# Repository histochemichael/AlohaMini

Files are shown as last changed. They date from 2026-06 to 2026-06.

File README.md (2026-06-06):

# AlohaMini2
 

AlohaMini2 is a dual-arm mobile robot with a motorized vertical lift — a major generational upgrade over AlohaMini1 while keeping the self-build BOM under $1,000.  

Fully 3D-printable on a Bambu P2S, built for embodied AI research, and priced for anyone serious about real-world manipulation.

> Assemble at home in ~120 minutes. Train or deploy with LeRobot.

## Updates

- [2026-06-06] AlohaMini2 released — 70 kg base load, 30 kg lift, 1 kg arm payload, 6+1 DoF, 52 cm reach, under $1,000 self-build BOM
- [2026-02-26] Fine-tuning and deployment guide for Pi 0.5 on AlohaMini (`examples/pi0.5_openpi`)
- [2025-12-18] URDF and simulation assets available (`AlohaMini1/simulation/src/Aloha/`)
- [2025-11-27] STEP (CAD) files available (`AlohaMini1/hardware/mobile_base/step/`)

## What's New in AlohaMini2

### Architecture

| | AlohaMini | AlohaMini2 |
|---|---|---|
| Arm system | [SO-ARM100 / SO-ARM101](https://github.com/TheRobotStudio/SO-ARM100) | [AM-ARM200](https://github.com/liyiteng/AM-ARM) |
| Mobile base system | [mobile_base1](AlohaMini1/hardware/mobile_base/) | [mobile_base2](AlohaMini2/hardware/mobile_base2/) |
| Printer requirement | Large-format FDM (>= 380 mm bed) | Bambu P2S (consumer-grade) |

### Performance

| | AlohaMini | AlohaMini2 |
|---|---|---|
| Base max load | 10 kg | 70 kg  |
| Lift capacity | 5 kg | 30 kg |
| Lift stability | Standard | Significantly reinforced |
| Arm payload | 0.3 kg | 1 kg |
| Arm reach | 40 cm | 52 cm |
| Arm DoF | 5+1 | 6+1 |
| Cameras | 5 | 5 (forward, backward, chest, dual wrist) |

AlohaMini2 is LeRobot-ready out of the box and remains fully open-source — hardware CAD, URDF, and software included.

## Gallery

<p align="center">
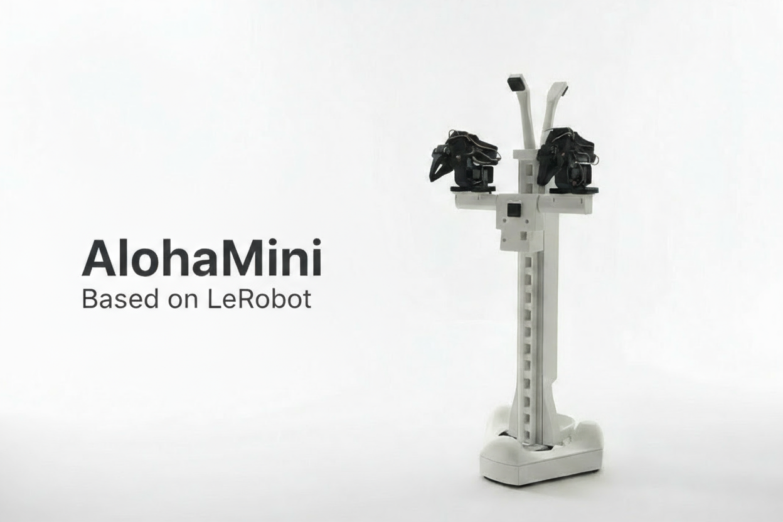
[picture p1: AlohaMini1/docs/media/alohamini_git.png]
  
</p>

## Bill of Materials (BOM)

| Component | Model / Notes | Qty | Unit Price (USD) |
|---|---|-----|---|
| Servo — standard | Feetech STS-3215 (12V, follower arms + base) | 11 | ~$16 |
| Servo — high-torque | Feetech STS-3095 (12V 95 kg·cm, lift + arm power joints) | 7 | ~$50 |
| Bus servo controllers | Waveshare | 2 | ~$5 |
| Compute | Raspberry Pi 5 (2 GB) | 1 | ~$93 |
| Cameras | 720p USB, 2.4 mm focal length | 5 | ~$17 |
| Omni wheels | 127 mm (74A) | 3 | ~$40 |
| Battery 12V | 11200 mAh Li-ion | 2 | ~$16 |
| Frame | 3D-printed on Bambu P2S | — | ~4 kg filament |
| **Total** | — | — | **~$950** |

> Full BOM with CN/US buy links: **[AlohaMini2/docs/BOM.md](AlohaMini2/docs/BOM.md)**  
> Compute can be swapped for Jetson Orin Nano or any SBC with USB 3.0.  

## Quick Start

1. **BOM** — review the component list and source parts  
   See **[Bill of Materials](AlohaMini2/docs/BOM.md)**

2. **3D Printing** — print all structural parts (~4 kg filament, Bambu P2S)  
   See **[Print Guide](AlohaMini2/docs/BOM.md#3d-printing)**

3. **Assembly** — build in ~60 minutes (arms pre-assembled)  
   See **[Assembly Guide](AlohaMini2/docs/assembly_guide.md)**

4. **Software setup & teleoperation** — install, connect, control  
   See **[Software Guide](software)**

## Product Line

| Model | Servo System | Chassis | Best For | Official Store (CN) |
|---|---|---|---|---|
| **AlohaMini2** | STS-3215 standard servos | 3D-printed base | Self-build research and development | [Taobao](https://item.taobao.com/item.htm?abbucket=9&id=1015799132286) |
| **AlohaMini2 Pro** | STS-3250 industrial-grade servos | Metal-reinforced base | Higher-duty research and lab use | [Taobao](https://item.taobao.com/item.htm?abbucket=9&id=1015799132286) |

## Contact

Email: liyiteng+github@gmail.com  
WeChat: liyiteng  
Videos & tutorials: Bilibili / YouTube / TikTok

## Team

AlohaMini is created by **Li Yiteng** and **Wu Zhiyong**.

## Acknowledgements

Thanks to the open robotics community:  
**ALOHA · LeKiwi · SO-ARM100 · SO-ARM100-Track-Axis · Pi-0.5 · LeRobot · Hugging Face**

## Support AlohaMini

If you find this project useful:
- Star the repo
- Follow for updates
- Join the community on Discord

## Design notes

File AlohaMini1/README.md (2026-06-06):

# AlohaMini
 

AlohaMini is a dual-arm mobile robot with a motorized vertical lift — beautifully designed, fully 3D-printable, and affordable.  

Built for embodied AI research and real-world manipulation. Assemble at home in ~60 minutes, customize every part, and train or deploy with LeRobot.

Note:
Use ROS only if you need URDF visualization, RViz inspection, or Gazebo simulation.

## Updates

- [2026-02-26] Update the fine-tuning and deployment guide for Pi 0.5 on Alohamini ('examples/pi0.5_openpi')
- [2025-12-18] URDF and simulation assets are now available for visualization and simulation (`simulation/src/Aloha/`)
- [2025-11-27] STEP (CAD) files are now available (`/hardware/mobile_base/step/`)

### What Makes It Different

- **Motorized vertical lift** — 0–60 cm travel (floor-to-table reach)
- **5-camera perception system** — top, front, back, and dual arm cameras engineered for embodied-AI reproducibility
- **Completely open-source** — hardware and software freely available
- **LeRobot-compatible** — works out of the box
- **Clean, modern design** — built for both function and aesthetics
- **Low-cost & accessible** — engineered so anyone can build a capable robot at home

## 📸 Gallery

<p align="center">
  
</p>

## ⚙️ Bill of Materials (BOM)
### Main Components

| Component | Model / Notes | Qty | Unit Price (USD) |
|---|---|-----|---|
| Servo motors | Feetech STS3215 (12V bus) | 16 | $13.89 |
| Motor control boards | Waveshare Bus Servo Adapter (A) | 2 | $10.55 |
| Compute platform | Raspberry Pi 5 (4/8GB) | 1 | $80 |
| Cameras | 720p USB cameras (2 for arms, 3 for mobile base) | 5 | $20 |
| Mobility system | Omni wheels | 3 | $36.00 |
| Battery | 12V Li-ion pack | 2 | $32.99 |
| Frame | 3D-printed body (ABS / PETG / PLA) | — | ~4kg filament (self-print) |
| **Total** | — | — | **~$600 (self-print)** |

Note: 
- Printable STL files under `/hardware/`
- Compute platform can be replaced with Jetson Nano or similar SBCs if desired.
- URDF files will be released soon

## Quick Start

Start building and running AlohaMini:

1. **Hardware acquisition** — Purchase components and 3D print parts  
   See **[BOM & 3D-Print](docs/BOM.md)**

1. **Assembly** — build the robot in ~60 minutes (SO-ARM pre-assembled)  
   See **[assembly guide](docs/hardware_assembly.md)**

1. **Software setup & teleoperation** — install, connect, and control the robot  
   See **[software guide](software)**

##  Product Line
| Model | Build | Rigidity | Target Users | Official Store (US) | Official Store (CN) |
|---|---|---|---|---|---|
| **AlohaMini** | Fully 3D-printed | Standard | Education, makers, research labs, home builds | - | [taobao](https://item.taobao.com/item.htm?abbucket=9&id=1015799132286) |
| **AlohaMini Pro** | Hybrid **3D-print + metal** | **~3×–5× stiffer** | Researchers needing plug-and-play, stable hardware | - | [taobao](https://item.taobao.com/item.htm?abbucket=9&id=1015799132286) |

> Same URDF & control stack across both versions — only structural materials differ.  
> Official store links are optional purchase channels for complete robots / kits.  
> AlohaMini remains open-source and can be self-built from the BOM, 3D-print files, and assembly docs.  

## Contact
Email: liyiteng+github@gmail.com  
WeChat: liyiteng  
Videos & tutorials soon on: Bilibili / YouTube / TikTok

## Team
AlohaMini is created by:  
**Li Yiteng** / **Wu Zhiyong**

##  Acknowledgements
Thanks to the open robotics community:  
**ALOHA · LeKiwi · SO-ARM100 · SO-ARM100-Track-Axis · Pi-0.5 · LeRobot · Hugging Face**

## ⭐ Support AlohaMini
If you like this project:
- ⭐ Star the repo  
- 🔔 Follow updates  
- 💬 Join the community

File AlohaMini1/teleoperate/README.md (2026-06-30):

# AlohaMini1 Teleoperation

This folder packages the scripts used to teleoperate an AlohaMini1 with:

- a Raspberry Pi controlling the mobile base, lift, and follower arms
- a PC controlling pedals/keyboard, phone or face steering, and SO-101 leader arms
- HTTP links between the PC and Pi

No personal IP addresses, Windows COM ports, or Pi `/dev/serial/by-id` paths are hardcoded in the commands. Replace placeholders such as `<PI_IP>`, `<PC_WIFI_IP>`, and `<LEFT_FOLLOWER_PORT>` with values from your own robot.

## Folder layout

```text
teleoperate/
  pc/
    combined_gyro_pedal_control_remote.py   # PC sender for base/lift plus gyro or face steering
    so101_leader_http_sender.py             # PC sender for one SO-101 leader arm
  pi/
    aloha_pi_follower_agent_pyserial.py     # Pi receiver for base/lift servos
    so101_follower_http_agent.py            # Pi receiver for one SO-101 follower arm
    aloha_camera_dashboard.py               # Optional Pi camera dashboard and recorder
  templates/
    commands.md                             # Copy/paste command templates with placeholders
    pi_ports.md                             # How to discover stable Pi serial ports
  requirements-pc-pedals.txt
  requirements-pi-base.txt
```

## Network architecture

```text
PC pedals/keys/steering -> Pi port 9000 -> base and lift
PC left leader arm      -> Pi port 9011 -> left follower arm
PC right leader arm     -> Pi port 9012 -> right follower arm
optional Pi cameras     -> Pi port 9100 -> browser dashboard
```

Run each receiver/sender in its own terminal while bringing the robot up. After the setup is stable, these commands can be wrapped in shell or batch scripts.

## What you must provide

These files do not include robot-specific calibration or hardware identity data. Each user must provide:

- Raspberry Pi IP address, found on the Pi with `hostname -I`
- PC Wi-Fi IPv4 address, found on Windows with `ipconfig`
- Pi serial paths, found with `ls -l /dev/serial/by-id/`
- Windows leader arm COM ports, found with `lerobot-find-port` or Device Manager
- LeRobot calibration files/IDs for each SO-101 leader and follower arm
- correct base/lift servo IDs and signs for your wiring
- optional camera `/dev/v4l/by-path/...` names if using the camera dashboard

The working prototype used base servo IDs `9`, `8`, `10` and lift ID `11`, but do not assume those match your robot.

## Optional hardware references

These are not strict requirements; they are examples of hardware used during bring-up or hardware in the same style.

- USB foot pedals for base/lift keyboard input: [Amazon example](https://www.amazon.com/dp/B0B1ZJVZ2K?ref=ppx_pop_mob_ap_share)
- Phone holder / VR-style adapter for phone steering: [Amazon example](https://www.amazon.com/dp/B0B1ZJVZ2K?ref=ppx_pop_mob_ap_share)
- Webcam for face steering: [Logitech C270 HD webcam](https://www.amazon.com/Logitech-Desktop-Widescreen-Calling-Recording/dp/B004FHO5Y6)

Any equivalent device should work if it presents itself to the PC as keyboard input for pedals, or securely holds the phone while the browser page streams orientation data.
<p align="center">
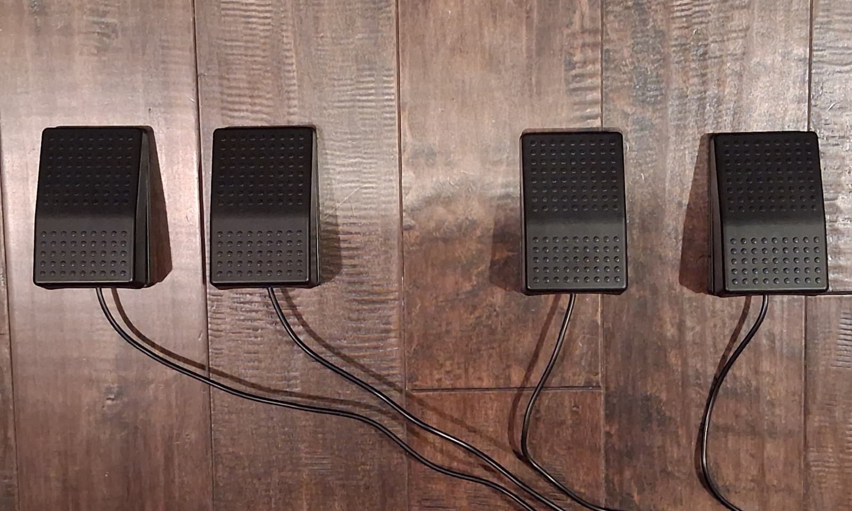
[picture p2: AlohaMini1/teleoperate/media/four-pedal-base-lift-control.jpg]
Four USB pedals for base and lift control
  
  <br>
  <sub>Four-pedal base and lift control layout.</sub>
</p>

## Dependencies

### Raspberry Pi

Use the same Python environment that has LeRobot working for your follower arms. Install base/lift dependencies:

```bash
python3 -m pip install -r requirements-pi-base.txt
```

The arm receiver also needs LeRobot and the Feetech/scservo SDK stack used by SO-101 followers. If your LeRobot install reports `scservo_sdk` errors, reinstall the Feetech-enabled LeRobot dependencies for your version.

The optional camera dashboard requires `ffmpeg`:

```bash
sudo apt update
sudo apt install ffmpeg
```

### PC

Use the same conda environment that has LeRobot working for your leader arms. For the pedal/keyboard/steering sender:

```bat
python -m pip install -r requirements-pc-pedals.txt
```

`opencv-python`, `mediapipe`, and `numpy` are only needed for `--steering-mode face`. Phone gyro steering and keyboard/pedal control need `pynput`.

## Calibration files

LeRobot looks up calibration by the `--robot-id` or `--leader-id` you pass to the scripts. If follower arms move from the PC to the Pi, copy the follower calibration files from the PC to the Pi.

Typical PC location:

```text
C:\Users\<YOU>\.cache\huggingface\lerobot\calibration\robots\so_follower\
```

Typical Pi location:

```bash
~/.cache/huggingface/lerobot/calibration/robots/so_follower/
```

Example copy command from Windows:

```bat
scp "C:\Users\<YOU>\.cache\huggingface\lerobot\calibration\robots\so_follower\<FOLLOWER_ID>.json" <PI_USER>@<PI_IP>:/home/<PI_USER>/.cache/huggingface/lerobot/calibration/robots/so_follower/
```

Leader calibration files stay on the PC if the leader arms stay plugged into the PC.

## Bring-up order

1. Put the robot on blocks or otherwise make it safe before first motion.
2. Start the Pi base/lift receiver and verify `curl http://127.0.0.1:9000/status`.
3. Start one Pi follower arm receiver and verify `curl http://127.0.0.1:9011/status`.
4. Start the matching PC leader sender at low FPS, e.g. `--fps 10`.
5. Move the leader slowly and confirm direction/range.
6. Repeat for the second arm on port `9012`.
7. Start the PC base/lift/steering sender.
8. Only after each channel works independently should you operate base, lift, and both arms together.

## Command templates

See [`templates/commands.md`](templates/commands.md) for full copy/paste commands.

The most important placeholders are:

```text
<PI_IP>                    Raspberry Pi IP from hostname -I
<PC_WIFI_IP>               Windows Wi-Fi IPv4 from ipconfig
<BASE_LIFT_PORT>           Pi /dev/serial/by-id path for the base/lift servo bus
<LEFT_FOLLOWER_PORT>       Pi /dev/serial/by-id path for the left follower arm
<RIGHT_FOLLOWER_PORT>      Pi /dev/serial/by-id path for the right follower arm
<LEFT_LEADER_COM_PORT>     Windows COM port for the left leader arm
<RIGHT_LEADER_COM_PORT>    Windows COM port for the right leader arm
```

## Phone steering notes

The phone gyro page is served by the PC sender at:

```text
http://<PC_WIFI_IP>:8765
```

A phone holder or VR-style adapter can make phone steering easier to keep centered while driving. One example is listed in [Optional hardware references](#optional-hardware-references).

Android Chrome may block device orientation on insecure HTTP origins. If motion events are unavailable, either allow sensors for that site in Chrome settings, use face steering, or add a touch/slider steering fallback.

## Face steering notes

Face steering uses the PC camera and these main parameters. A standard USB webcam works; the optional hardware list includes one example used for this style of setup:

```text
--steering-mode face
--face-camera 0
--face-deadband 15
--face-max-yaw 40
--face-smoothing 0.2
--face-preview
```

Increase `--face-deadband` if tiny head movements cause unwanted turning. Increase/decrease `--turn-speed` to scale robot turning speed.
<table>
  <tr>
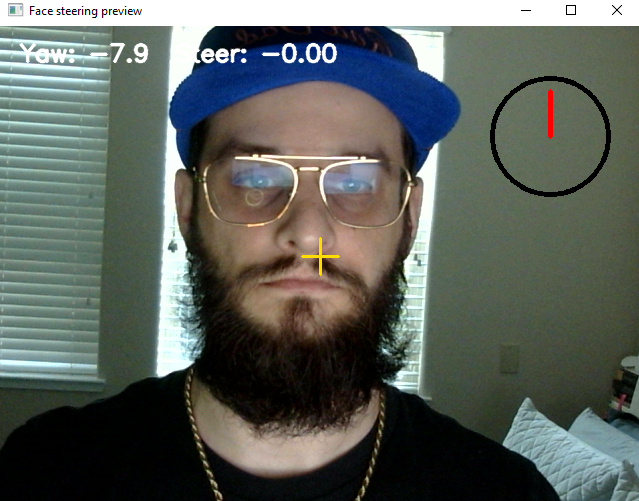
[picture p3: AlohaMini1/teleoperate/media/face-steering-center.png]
Center steering face position
    <td align="center"></td>
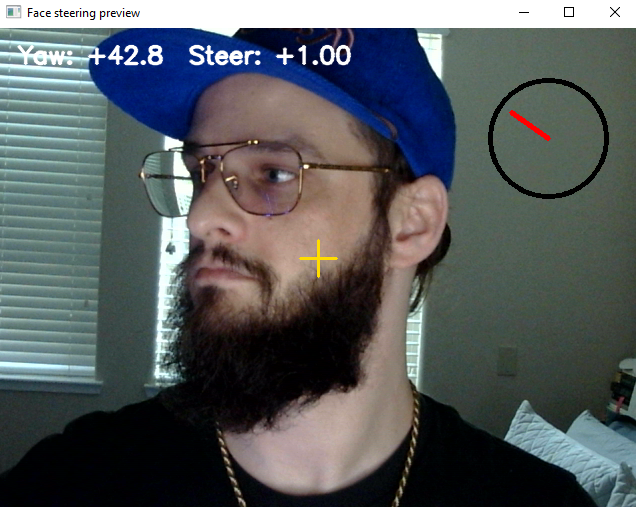
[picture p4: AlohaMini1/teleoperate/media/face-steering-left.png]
Left steering face position
    <td align="center"></td>
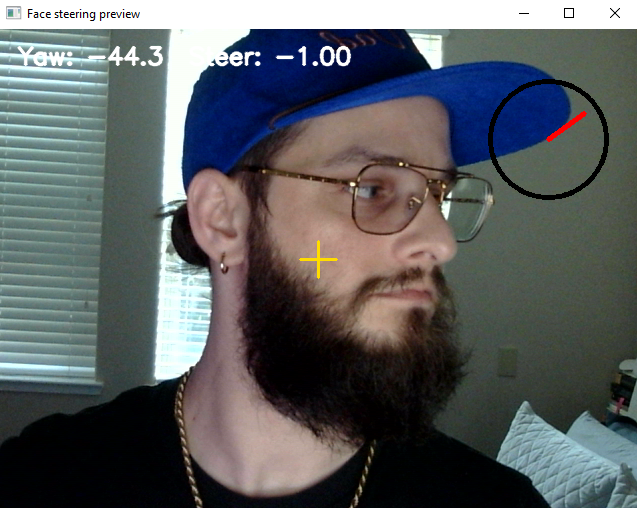
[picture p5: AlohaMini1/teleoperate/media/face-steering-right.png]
Right steering face position
    <td align="center"></td>
  </tr>
  <tr>
    <td align="center"><strong>Center steering</strong></td>
    <td align="center"><strong>Left steering</strong></td>
    <td align="center"><strong>Right steering</strong></td>
  </tr>
</table>

## Safety controls

- Stop any terminal with `Ctrl+C`.
- The PC base/lift sender sends `/stop` on exit.
- The Pi base/lift receiver has a watchdog timeout and stops if commands stop arriving.
- Use `--activation-threshold` on arm receivers so follower arms do not move until the leader has moved away from the startup pose.
- Start with `--fps 10` for arms, then increase only after the mapping is verified.

## Scripts recovered from the working prototype

The packaged scripts correspond to the working split-PC/Pi teleoperation setup:

- `combined_gyro_pedal_control_remote.py` from the PC sender setup
- `so101_leader_http_sender.py` from the PC leader bridge
- `aloha_pi_follower_agent_pyserial.py` from the Pi base/lift receiver
- `so101_follower_http_agent.py` from the Pi follower arm receiver
- `aloha_camera_dashboard.py` from the optional Pi camera dashboard

If your local robot has newer versions, compare before replacing these. The bridge scripts include import fallbacks for the two LeRobot module layouts observed during bring-up: `so_*` and `so101_*`.

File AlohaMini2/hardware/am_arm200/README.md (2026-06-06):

# AM-ARM200

AlohaMini2 uses AM-ARM200 as its follower and leader arm platform.

The arm CAD, assembly guide, firmware notes, and updates are maintained in the upstream repository:

**[liyiteng/AM-ARM](https://github.com/liyiteng/AM-ARM)**

Use the AM-ARM200 documentation there when building or modifying the arms for AlohaMini2.

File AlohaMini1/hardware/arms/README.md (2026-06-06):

This arm design is based on Lekiwi (base) and SO100 (arm structure).
We merged and adapted the two projects for the AlohaMini platform.
Huge thanks to the original creators for their excellent work.

Original projects:

- Lekiwi: https://github.com/SIGRobotics-UIUC/LeKiwi

- SO100: https://github.com/TheRobotStudio/SO-ARM100

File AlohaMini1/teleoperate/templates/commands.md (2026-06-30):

# Command Templates

Replace every value in angle brackets before running.

## Raspberry Pi

### Terminal 1: base and lift receiver

```bash
cd <PATH_TO_AlohaMini>/AlohaMini1/teleoperate/pi
python3 -u aloha_pi_follower_agent_pyserial.py \
  --servo-port <BASE_LIFT_PORT> \
  --port 9000 \
  --front-id <FRONT_BASE_SERVO_ID> \
  --back-left-id <BACK_LEFT_BASE_SERVO_ID> \
  --back-right-id <BACK_RIGHT_BASE_SERVO_ID> \
  --lift-id <LIFT_SERVO_ID> \
  --setup-velocity-mode
```

The working prototype used base servo IDs `9`, `8`, `10` and lift ID `11`, but verify your own wiring.

### Terminal 2: left follower arm receiver

```bash
cd <PATH_TO_AlohaMini>/AlohaMini1/teleoperate/pi
python3 -u so101_follower_http_agent.py \
  --follower-port <LEFT_FOLLOWER_PORT> \
  --port 9011 \
  --robot-id <LEFT_FOLLOWER_CALIBRATION_ID> \
  --max-relative-target 10 \
  --activation-threshold 1.0
```

### Terminal 3: right follower arm receiver

```bash
cd <PATH_TO_AlohaMini>/AlohaMini1/teleoperate/pi
python3 -u so101_follower_http_agent.py \
  --follower-port <RIGHT_FOLLOWER_PORT> \
  --port 9012 \
  --robot-id <RIGHT_FOLLOWER_CALIBRATION_ID> \
  --max-relative-target 10 \
  --activation-threshold 1.0
```

### Optional Terminal 4: camera dashboard

Edit `pi/aloha_camera_dashboard.py` first and replace the `CAMERAS` paths with your own `/dev/v4l/by-path/...` names.

```bash
cd <PATH_TO_AlohaMini>/AlohaMini1/teleoperate/pi
python3 -u aloha_camera_dashboard.py --host 0.0.0.0 --port 9100 --width 640 --height 480 --fps 5
```

Open from the PC at `http://<PI_IP>:9100`.

## PC

### Terminal 1: base, lift, and steering sender

Optional hardware references:

- USB foot pedals for keyboard-style base/lift input: https://www.amazon.com/dp/B0B1ZJVZ2K?ref=ppx_pop_mob_ap_share
- Phone holder / VR-style adapter for phone steering: https://www.amazon.com/dp/B0B1ZJVZ2K?ref=ppx_pop_mob_ap_share

```bat
conda activate <PEDAL_ENV>
cd <PATH_TO_AlohaMini>\AlohaMini1\teleoperate\pc
python combined_gyro_pedal_control_remote.py --host 0.0.0.0 --pc-host-hint <PC_WIFI_IP> --robot-host <PI_IP> --robot-port 9000 --web-port 8765 --turn-speed 600 --invert-turn --base-forward-key d --base-backward-key f --lift-up-key a --lift-down-key s --base-speed 3000 --lift-speed 1000 --stream-commands
```

Phone gyro steering page:

```text
http://<PC_WIFI_IP>:8765
```

Face steering alternative:

```bat
python combined_gyro_pedal_control_remote.py --robot-host <PI_IP> --robot-port 9000 --web-port 8765 --turn-speed 600 --invert-turn --base-forward-key d --base-backward-key f --lift-up-key a --lift-down-key s --base-speed 1500 --lift-speed 1000 --stream-commands --steering-mode face --face-camera 0 --face-deadband 15 --face-max-yaw 40 --face-smoothing 0.2 --face-preview --request-timeout 2.0
```

### Terminal 2: left leader arm sender

```bat
conda activate <LEROBOT_ENV>
cd <PATH_TO_AlohaMini>\AlohaMini1\teleoperate\pc
python so101_leader_http_sender.py --leader-port <LEFT_LEADER_COM_PORT> --leader-id <LEFT_LEADER_CALIBRATION_ID> --robot-url http://<PI_IP>:9011 --fps 10
```

### Terminal 3: right leader arm sender

```bat
conda activate <LEROBOT_ENV>
cd <PATH_TO_AlohaMini>\AlohaMini1\teleoperate\pc
python so101_leader_http_sender.py --leader-port <RIGHT_LEADER_COM_PORT> --leader-id <RIGHT_LEADER_CALIBRATION_ID> --robot-url http://<PI_IP>:9012 --fps 10
```

## Status checks

On the Pi:

```bash
curl http://127.0.0.1:9000/status
curl http://127.0.0.1:9011/status
curl http://127.0.0.1:9012/status
```

On the PC:

```bat
curl http://<PI_IP>:9000/status
curl http://<PI_IP>:9011/status
curl http://<PI_IP>:9012/status
powershell -Command "Test-NetConnection <PI_IP> -Port 9000"
powershell -Command "Test-NetConnection <PI_IP> -Port 9011"
powershell -Command "Test-NetConnection <PI_IP> -Port 9012"
```

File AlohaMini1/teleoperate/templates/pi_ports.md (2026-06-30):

# Pi Port Discovery

Run these on the Raspberry Pi after plugging in the base/lift controller and follower arm controllers:

```bash
ls -l /dev/serial/by-id/
ls -l /dev/ttyACM* /dev/ttyUSB*
```

Prefer `/dev/serial/by-id/...` paths in commands because `/dev/ttyACM0`, `/dev/ttyACM1`, etc. can change after reboot or replugging.

If you need to identify which physical controller is which, plug in one USB controller at a time and run:

```bash
udevadm info -q property -n /dev/ttyACM1 | grep -E 'ID_SERIAL=|ID_SERIAL_SHORT=|ID_MODEL=|ID_VENDOR=|DEVPATH='
ls -l /dev/serial/by-id/
```

Write down the mapping:

```text
BASE_LIFT_PORT=/dev/serial/by-id/...
LEFT_FOLLOWER_PORT=/dev/serial/by-id/...
RIGHT_FOLLOWER_PORT=/dev/serial/by-id/...
```

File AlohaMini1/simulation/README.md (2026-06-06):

# AlohaMini-Simulation

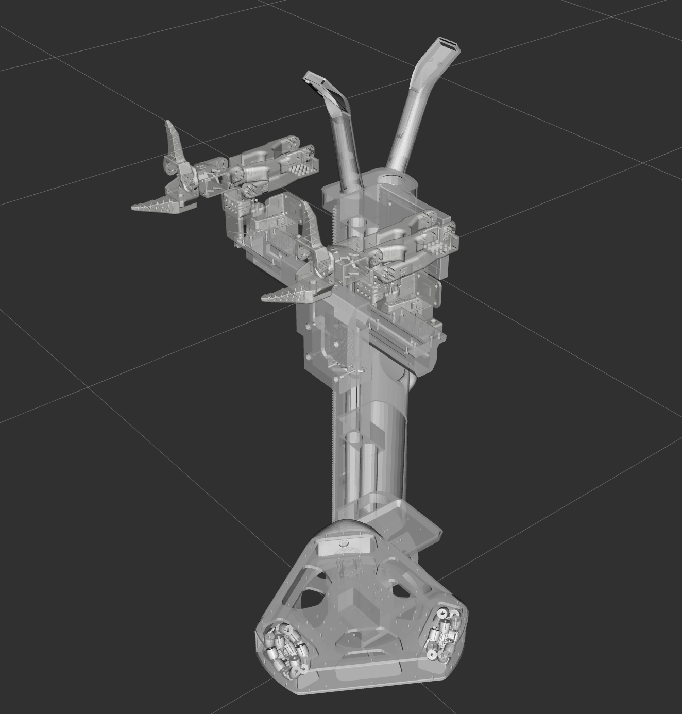
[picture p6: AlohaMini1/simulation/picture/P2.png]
AlohaMini preview


This directory contains the simulation and visualization assets for **AlohaMini**. It provides dual-stack support for both **ROS 1** and **ROS 2**, enabling high-fidelity visualization in RViz and physics-based testing in Gazebo.

## ROS 2 — Build & Run (colcon)

These instructions target ROS 2 (colcon-based workspaces). Adjust the distro names (Foxy/Galactic/Humble/Jazzy) as needed.

1) Install prerequisites (example):

```bash
# install colcon and ros dependencies (example for Ubuntu)
sudo apt update
sudo apt install -y python3-colcon-common-extensions python3-rosdep
```

2) Build the workspace:

```bash
cd simulation
colcon build
```

3) Source the overlay before running:

```bash
source install/setup.bash
```

4) (Optional) Force FastDDS as the RMW implementation:

```bash
export RMW_IMPLEMENTATION=rmw_fastrtps_cpp
```

5) Run RViz2 visualization (example):

```bash
ros2 launch Aloha display.launch.py  # RViz2 visualization
```

Notes for ROS 2:
- Ensure you installed ROS 2 for your target distro and that `source /opt/ros/<distro>/setup.bash` is present in your shell if needed.
- If using mixed ROS1/ROS2 setups, configure the ROS1-ROS2 bridge separately.

## ROS 1 — Build & Run (catkin)

These instructions target ROS 1 (catkin-based workspaces) such as Melodic or Noetic.

1) Create a catkin workspace and place the repository in `src`:

```bash
mkdir -p ~/catkin_ws/src
cd ~/catkin_ws/src
# assuming AlohaMini repository is already cloned
ln -s /path/to/AlohaMini/simulation ~/catkin_ws/src/Aloha
cd ~/catkin_ws
```

2) Install and resolve dependencies with `rosdep`:

```bash
sudo apt update
sudo apt install -y python3-rosdep
sudo rosdep init   # only if rosdep isn't initialized yet
rosdep update
rosdep install --from-paths src --ignore-src -r -y
```

3) Build with `catkin_make`:

```bash
catkin_make
source devel/setup.bash
```

Or build with `catkin_tools` (`catkin build`):

```bash
sudo apt install -y python3-catkin-tools
cd ~/catkin_ws
catkin build
source devel/setup.bash
```

4) Run ROS 1 launch files:

```bash
roslaunch Aloha display.launch       # RViz visualization
roslaunch Aloha gazebo.launch        # Gazebo visualization
```

Notes for ROS 1:
- These commands are intended for Linux (Ubuntu). For Windows, use WSL or a Linux VM for better ROS1 support.
- If you see missing packages, double-check that package names and dependencies match your ROS distro (Melodic vs Noetic).

## Troubleshooting

- If RViz/RViz2 does not show robot models, ensure `robot_state_publisher` is running and `/tf` topics are being published.
- For mixed ROS1/ROS2 systems, verify your ROS1-ROS2 bridge configuration and topic remapping.
- If launches fail due to missing dependencies, run `rosdep install --from-paths src --ignore-src -r -y` in the workspace root.

## Acknowledgements
This module was originally developed as a standalone repository,
**lemon198/AlohaMini-Simulation**, and later integrated into the main **AlohaMini** project.

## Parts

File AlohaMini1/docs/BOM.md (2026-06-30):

# Bill of Materials

AlohaMini follows the same architecture and terminology as LeKiwi, consisting of a Client side and a Host side.

- The Client handles computation and control.
- The Host executes commands and returns observations.

This is also commonly referred to as PC side vs. Remote side, and both naming conventions are equivalent.

AlohaMini’s Client hardware includes the mobile base and two follower arms. The arms directly reuse the SO-ARM100 design. Therefore, if you already have two SO-ARM100 arms, you only need to assemble the mobile base. Communication between the mobile base, arms, and Raspberry Pi 5 uses the same bus-servo communication system, and the build guide will explain the wiring in detail.

On AlohaMini, the Host side consists of a PC workstation and leader arms. VR controllers or other devices can also replace the leader arms, and we will release compatible controller kits soon. For beginners, we recommend starting with leader-arm teleoperation.

*Note: Table clamp, screwdriver set, soldering iron, and other common tools can be sourced as needed and are not listed in the tables below.*

## Mobile base 

| Item | Model / Notes | Qty | Unit Cost (US) | Buy (US) | Unit Cost (CN) | Buy (CN) |
|---|---|-----|---|---|---|---|
| Servo motor | Feetech / 12V 1/345 Gear(STS3215-C018)| 4 | $13.89 | [Alibaba](https://www.alibaba.com/product-detail/Feetech-12V-1-345-STS3215-C018_1601637205886.html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) | ¥110 | [taobao](https://item.taobao.com/item.htm?id=996544351583&spm=a213gs.v2success.0.0.73c04831naDrHP) |
| Omni wheel | 4″ (≈100 mm) | 3 | $47 | [Amazon](https://www.amazon.com/Replacement-Plastic-Directional-Accessories-Platform/dp/B0F9W6QX5M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) | ¥135 | [pinduoduo](https://mobile.yangkeduo.com/goods.html?ps=kKWPC7xuzw) |
| USB camera | 720p focal length 2.4 mm, 36×36 mm form factor | 3 | — | [Amazon](https://www.amazon.com/dp/B0FXWWF55X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) | ¥125 | [taobao](https://item.taobao.com/item.htm?id=666278411821) |
| 4-port USB hub | USB hub for cameras, servo controllers, and accessories | 2 | — | [Amazon](https://www.amazon.com/dp/B00BWF5U0M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) | — | — |
| Touchscreen monitor | 7-inch touchscreen monitor for the Raspberry Pi / onboard dashboard | 1 | — | [Amazon](https://www.amazon.com/dp/B09XKC53NH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) | — | — |
| (optional) Bearing | 12×18×4 mm (ID × OD × W) — wheel axle bearing | 3 | — | Amazon | ¥6 | [tmall](https://detail.tmall.com/item.htm?id=824704356695) |
| Bearing | 4×13×5 mm (ID × OD × W) — lift axis bearing | 8 | — | Amazon | ¥3 | [taobao](https://item.taobao.com/item.htm?id=565418362178) |
| M2×12 hex socket screw | For camera mounts (OB_T_Camera_Mount.stl, OB_Top_Camera_Mount) | 12 | — | — | — | — |
| M2.5×12 hex socket screw | For optional camera covers and spacers | 6 | — | — | — | — |
| M3×12 hex socket screw | Total 36 pcs (Servo Mount×24 ,Side Panel×12 ) | 36 | — | — | — | — |
| M3×16 hex socket screw | For optional touchscreen monitor enclosure | 4 | — | — | — | — |
| M3×18 hex socket screw | For OB_Chassis_Wheel_Axle_Connector.stl | 12 | — | — | — | — |
| M3×30 hex socket screw | For OB_T_Connector_Right/Left.stl | 8 | — | — | — | — |
| M3 hex nut | For OB_T_Connector_Right/Left.stl | 8 | — | — | — | — |
| M3x5x4 heat-set insert | Total 36 pcs (Servo Mount×24, Side Panel×12) | 36 | — | Amazon | ¥5 | [taobao](https://item.taobao.com/item.htm?id=809241671998) |
| M4×12 hex socket screw | Total 20 pcs (Bearing Cover×12, Z-axis Servo Mount×8) | 20 | — | Amazon | — | — |
| M4x6x5 heat-set insert | For OB_Chassis_Bearing_Cover.stl | 12 | — | Amazon | ¥4 | [taobao](https://item.taobao.com/item.htm?id=809241671998) |
| Adhesive | Epoxy (strongly recommended) / double-sided tape — cable retention & structural bonding | 1 | — | Amazon | ¥12 | [jd](https://item.jd.com/100141557259.html) |
| Servo extension cable | SCS 3-pin, 90 cm | 2 | — | [Alibaba](https://www.alibaba.com/product-detail/3P-5264-Interface-Bus-Actuator-Connection_1601635790774.html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) | ¥3 | [taobao](https://item.taobao.com/item.htm?id=616460581906) |
| Battery | 12 V Li-ion pack with 5521 barrel jack (male & female); one pack for the Raspberry Pi 5, the other for the mobile base and follower arms.| 2 | $43 | [Amazon](https://www.amazon.com/KBT-Rechargeable-Connector-Replacement-Security/dp/B0C242DYT1/ref=sr_1_2_sspa?th=1) | ¥130 | [taobao](https://item.taobao.com/item.htm?id=890828103056) |
| USB Type-C cable | Only for testing the mobile base | 1 | $10 | [Amazon](https://www.amazon.com/Charging-etguuds-Charger-Braided-Compatible/dp/B0B8NWLLW2/?th=1) | ¥20 | [tmall](https://detail.tmall.com/item.htm?id=754024805047) |
| Waveshare Bus Servo Controller | Only for testing the mobile base | 1 | $13 | [Amazon](https://www.amazon.com/Waveshare-Integrates-Control-Circuit-Supports/dp/B0CTMM4LWK/) | ¥27 | [tmall](https://detail.tmall.com/item.htm?id=738817173460) |
| 3D-printed parts | PLA/PETG/ABS (files in /hardware/mobile_base/stl) | ~4 kg filament | — | — | — | — |

**3D Printing Parts List:**
- OB_Chassis_Bearing_Cover x3
- OB_Chassis_Servo_Mount x3
- OB_Chassis_Side_Panel x3
- OB_Chassis_Wheel_Axle_Connector x3
- OB_Chassis_Wheel_Guard x3
- OB_Top_Camera_Back_Cover x2
- OB_Chassis_Shaft_Sleeve_12_24 x3
- O_Chassis_Dowel_Pin_12_37 x3
- All other files x1

Note：
All other parts — including the lift mechanism — can be printed on a standard 3D printer. Only the chassis is special, as it requires a build volume of at least 385 × 345 × 64 mm. We recommend choosing a machine with around 400 × 360 × 100 mm or larger. Due to its size, the chassis may need to be outsourced for printing.

### What the Base Can Do

With only the components above, you can assemble the **mobile base** and control:

- movement  
- vertical lift  

Use the following commands to control the base:
```bash
python examples/debug/wheels.py \
   --port /dev/ttyACM0

python examples/debug/axis.py \
   --port /dev/ttyACM0
```

Use W/S/A/D to drive the base, and U/J to raise or lower the lift — all directly from your PC, without installing any single-board computer on the robot.

More details will be provided in the software setup section.

Effect after assembly:

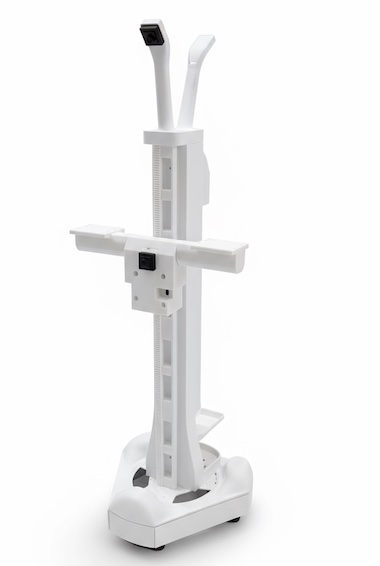
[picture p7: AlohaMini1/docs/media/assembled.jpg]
Assembled AlohaMini mobile base

### Standalone Mode (Optional)

If you prefer the base to operate as an **independent host system** (Wi‑Fi, untethered), add:

| Item | Model / Notes | Qty | Unit Cost (US) | Buy (US) | Unit Cost (CN) | Buy (CN) |
|---|---|-----|---|---|---|---|
| Compute board | Raspberry Pi 5 (≥ 2GB RAM) | 1 | $80 | [Adafruit](https://www.adafruit.com/product/5812) | ¥600 | [taobao](https://item.taobao.com/item.htm?id=688878446695) |
| DC converter | 12V → 5V / 5A buck converter | 1 | $13 | [Amazon](https://www.amazon.com/Klnuoxj-Converter-Interface-Waterproof-Compatible/dp/B0CRVW7N2J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) | ¥75 | [taobao](https://item.taobao.com/item.htm?id=800698078303) |
| Monitor | 7-inch HD IPS HDMI interface + touch + Type C power supply | 1 | — | Amazon | ¥291 | [taobao](https://item.taobao.com/item.htm?id=592070943040) |

## Optional Teleoperation Accessories

These accessories are not required for the base mechanical build, but they were used for the optional teleoperation setup described in `AlohaMini1/teleoperate`.

| Item | Model / Notes | Qty | Unit Cost (US) | Buy (US) | Unit Cost (CN) | Buy (CN) |
|---|---|-----|---|---|---|---|
| Webcam for face steering | Logitech C270 or equivalent USB webcam | 1 | — | [Amazon](https://www.amazon.com/Logitech-Desktop-Widescreen-Calling-Recording/dp/B004FHO5Y6?th=1) | — | — |
| VR goggles / phone holder for steering | Phone holder for gyro-based steering; use as an alternative to face steering | 1 | — | [Amazon](https://www.amazon.com/dp/B0G5QGFSPV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) | — | — |
| USB foot pedals | Four pedals mapped to base forward/backward and lift up/down | 4 | — | [Amazon](https://www.amazon.com/dp/B0B1ZJVZ2K?ref=ppx_pop_mob_ap_share) | — | — |

## Follower Arms
| Item | Model / Notes | Qty | Unit Cost (US) | Buy (US) | Unit Cost (CN) | Buy (CN) |
|---|---|-----|---|---|---|---|
| Servo motor | Feetech / 12V 1/345 Gear(STS3215-C018) | 12 | $13.89 | [Alibaba](https://www.alibaba.com/product-detail/Feetech-12V-1-345-STS3215-C018_1601637205886.html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) | ¥110 | [taobao](https://item.taobao.com/item.htm?id=996544351583&spm=a213gs.v2success.0.0.73c04831naDrHP) |
| Waveshare Bus Servo Controller | For connecting to the Raspberry Pi 5 | 2 | $13 | [Amazon](amazon.com/Waveshare-Integrates-Control-Circuit-Supports/dp/B0CTMM4LWK/) | ¥27 | [tmall](https://detail.tmall.com/item.htm?id=738817173460) |
| USB camera | 720p focal length 3.8 mm, 32×32 mm form factor | 2 | — | Amazon | ¥103 | [taobao](https://item.taobao.com/item.htm?id=590682120464) |
| 1-to-2 DC splitter cable | 30 cm, 5521 connector — for powering the arms | 1 | — | Amazon | ¥5 | [taobao](https://item.taobao.com/item.htm?id=594921965049) |
| DC extension cable | 1.5 m, 5521 connector — for powering the arms | 2 | — | Amazon | ¥2.50 | [taobao](https://item.taobao.com/item.htm?id=43628177900) |
| USB Type-C cable | For connecting to the Raspberry Pi 5 | 2 | $10 | [Amazon](https://www.amazon.com/Charging-etguuds-Charger-Braided-Compatible/dp/B0B8NWLLW2/?th=1) | ¥20 | [tmall](https://detail.tmall.com/item.htm?id=754024805047) |
| 3D-printed parts | PLA/PETG/ABS (files in /hardware/arms/stl) | 1 set | — | — | — | — |

**3D Printing Parts List:**
- All "D_*.stl" files: x2
- All "F_*.stl" files: x2

For detailed printing instructions, refer to the [SO-ARM100 project README](https://github.com/TheRobotStudio/SO-ARM100)

## Leader Arms
> **Note:** The official SO-ARM100 design uses three different gear ratios (1/147, 1/191, 1/345) for optimal performance. However, our testing shows that using a single gear ratio (1/147) provides excellent user experience and significantly simplifies assembly. The BOM below reflects this simplified configuration.

| Item | Model / Notes | Qty | Unit Cost (US) | Buy (US) | Unit Cost (CN) | Buy (CN) |
|---|---|-----|---|---|---|---|
| Servo motor | Feetech / 7.4V 1/147 Gear(STS3215-C046) | 12 | $13.89 | [Alibaba](https://www.alibaba.com/product-detail/Feetech-STS3215-Servos-Feetech-7-4V_1601636218844.html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) | ¥99 | [taobao](https://item.taobao.com/item.htm?id=996544351583&spm=a213gs.v2success.0.0.73c04831naDrHP) |
| Waveshare Bus Servo Controller | For connecting to the PC | 2 | $13 | [Amazon](https://www.amazon.com/Waveshare-Integrates-Control-Circuit-Supports/dp/B0CTMM4LWK/) | ¥27 | [tmall](https://detail.tmall.com/item.htm?id=738817173460) |
| Battery | 5V Li-ion pack (5600mAh, DC 5521 connector) | 1 | — | Amazon | ¥30 | [taobao](https://item.taobao.com/item.htm?id=765749120668) |
| 1-to-2 DC splitter cable | 70 cm — for powering the arms | 1 | — | Amazon | ¥5 | [taobao](https://item.taobao.com/item.htm?id=594921965049) |
| USB Type-C cable | For connecting to the PC | 2 | $10 | [Amazon](https://www.amazon.com/Charging-etguuds-Charger-Braided-Compatible/dp/B0B8NWLLW2/?th=1) | ¥20 | [tmall](https://detail.tmall.com/item.htm?id=754024805047) |
| 3D-printed parts | PLA/PETG/ABS (files in /hardware/arms/stl) | 1 set | — | — | — | — |

**3D Printing Parts List:**
- All "D_*.stl" files: x2
- All "L_*.stl" files: x2

For detailed printing instructions, refer to the [SO-ARM100 project README](https://github.com/TheRobotStudio/SO-ARM100)

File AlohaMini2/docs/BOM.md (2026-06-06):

# Bill of Materials — AlohaMini2

AlohaMini2 follows the same Client/Host architecture as LeKiwi:

- **Host** — mobile base + follower arms + compute (Raspberry Pi 5)
- **Client** — PC workstation + leader arms

> Common tools (table clamp, soldering iron, screwdriver set) are not listed.

---

## Mobile Base

| Item | Spec | Qty | Unit ($) | Buy (US) | Unit (¥) | Buy (CN) |
|---|---|----:|---:|---|---:|---|
| Servo — STS-3215 (wheel) | ST-3215-C018, 12V, 1/345 gear | 3 | $15.97 | [Alibaba](https://www.alibaba.com/product-detail/Lerobot-360-Degree-Smart-Servo-for_1601563310522.html) | ¥110 | [Taobao](https://e.tb.cn/h.64H9u3maGWzIp5Q?tk=T5liexkG6Yz) |
| Servo — STS-3095 (lift) | ST-3095-C002, 12V, 95 kg·cm | 1 | $50.37 | [Alibaba](https://www.alibaba.com/product-detail/FEETECH-STS3095-12V-95KG-servo-AI_1601045980686.html) | ¥345 | [Taobao](https://item.taobao.com/item.htm?abbucket=18&id=764857479703) |
| Omni wheel | 127 mm (74A) | 3 | $40 | [omniawheel.com](https://www.omniawheel.com/) | ¥289 | [Taobao](http://e.tb.cn/h.R5jm5Xlk56vjQRJ) |
| Aluminum extrusion (T-frame) | 20×40×2 mm, L=400 mm *(or print `O_T_Connector_Cross_Bar.stl`)* | 1 | ~$1.50 | — | ¥10 | — |
| Steel pin (chassis) | Φ12×80 mm *(or print `O_Chassis_Dowel_Pin_12_80.stl`)* | 3 | ~$0.50 | Amazon | ¥3.28 | [Taobao](https://e.tb.cn/h.ivppuOirL8K8zsH?tk=IKNy5kRfNCm) |
| Steel pin (lift axis) | Φ12×25 mm *(or print `O_T_Connector_Dowel_Pin_12_25.stl`)* | 1 | ~$0.50 | Amazon | ¥3.28 | [Taobao](https://e.tb.cn/h.ivppuOirL8K8zsH?tk=IKNy5kRfNCm) |
| Bearing — lift track | 4×13×5 mm | 8 | ~$0.40 | Amazon | ¥3 | [Taobao](https://item.taobao.com/item.htm?id=565418362178) |
| Bearing — chassis/arm/lift | 12×18×4 mm | 8 | ~$0.80 | [Amazon](https://www.amazon.com/XIKE-6701-2RS-Bearings-12x18x4mm-Pre-Lubricated/dp/B09D2RQ4Y1) | ¥6 | [Tmall](https://detail.tmall.com/item.htm?id=824704356695) |
| Camera — front | H65V1, 720p, 2.4 mm, 1 m cable | 1 | ~$17 | Amazon | ¥122 | [Taobao](https://item.taobao.com/item.htm?id=666278411821) |
| Camera — back | H65V1, 720p, 2.4 mm, 1 m cable | 1 | ~$17 | Amazon | ¥122 | [Taobao](https://item.taobao.com/item.htm?id=666278411821) |
| Camera — chest | H65V1, 720p, 2.4 mm, 2 m cable | 1 | ~$17 | Amazon | ¥122 | [Taobao](https://item.taobao.com/item.htm?id=666278411821) |
| Raspberry Pi 5 | 2 GB RAM | 1 | ~$93 | [Adafruit](https://www.adafruit.com/product/5812) | ¥669 | [Taobao](https://item.taobao.com/item.htm?id=688878446695) |
| DC buck converter | 12V→5V 5A (PD protocol) | 1 | ~$9 | [Amazon](https://www.amazon.com/Klnuoxj-Converter-Interface-Waterproof-Compatible/dp/B0CRVW7N2J) | ¥66 | [Taobao](https://item.taobao.com/item.htm?id=800698078303) |
| Heatsink | Raspberry Pi 5 (passive) | 1 | ~$2.50 | Amazon | ¥18 | [Taobao](https://item.taobao.com/item.htm?id=755560852039) |
| microSD card | 32 GB | 1 | ~$14 | Amazon | ¥99.9 | — |
| HDMI→Micro HDMI cable | 1 m, 4K60Hz | 1 | ~$1 | Amazon | ¥7 | [pinduoduo](https://mobile.yangkeduo.com/goods.html?ps=9DevREvDAj) |
| Bus servo controller | Waveshare Bus Servo Adapter A | 1 | $5.00 | [Waveshare](https://www.waveshare.com/bus-servo-adapter-a.htm) | ¥27 | [Tmall](https://detail.tmall.com/item.htm?id=738817173460) |
| Battery 12V | 11200 mAh, DC 5521 | 2 | ~$16 | [Amazon](https://www.amazon.com/KBT-Rechargeable-Connector-Replacement-Security/dp/B0C242DYT1/) | ¥114 | [Taobao](https://item.taobao.com/item.htm?id=890828103056) |
| DC splitter cable | 1-to-2, 30 cm | 1 | ~$0.60 | Amazon | ¥4.5 | [Taobao](https://e.tb.cn/h.ivLJNFtMOZ50iFx?tk=GN8V5ki58UN) |
| DC extension cable | 1 m | 2 | ~$0.30 | Amazon | ¥2.3 | [Taobao](https://e.tb.cn/h.iucAEva43LkxQz1?tk=INAY5k79Qyz) |
| Servo extension cable | 90 cm, Feetech 3-pin | 2 | ~$0.30 | [Alibaba](https://www.alibaba.com/product-detail/3P-5264-Interface-Bus-Actuator-Connection_1601635790774.html) | ¥2 | Feetech channel |
| 3D-printed parts | PLA/PETG/ABS, Bambu P2S | — | ~4 kg filament | — | — | `/AlohaMini2/hardware/mobile_base/stl/` |

---

## Follower Arms (×2)

Each arm: **6+1 DoF, 52 cm reach, 1 kg payload** — based on AM-ARM200.

| Item | Spec | Qty | Unit ($) | Buy (US) | Unit (¥) | Buy (CN) |
|---|---|----:|---:|---|---:|---|
| Servo — STS-3215 | ST-3215-C018, 12V, 1/345 gear | 8 | $15.97 | [Alibaba](https://www.alibaba.com/product-detail/Lerobot-360-Degree-Smart-Servo-for_1601563310522.html) | ¥110 | [Taobao](https://e.tb.cn/h.64H9u3maGWzIp5Q?tk=T5liexkG6Yz) |
| Servo — STS-3095 | ST-3095-C002, 12V, 95 kg·cm | 6 | $50.37 | [Alibaba](https://www.alibaba.com/product-detail/FEETECH-STS3095-12V-95KG-servo-AI_1601045980686.html) | ¥345 | [Taobao](https://item.taobao.com/item.htm?abbucket=18&id=764857479703) |
| Hex socket screw M3×10 | 100-pack | 2 packs | — | — | ¥6 | [Taobao](https://e.tb.cn/h.R0nMFj8y9riNyJl?tk=HNii5rHz4NJ) |
| Heat-set insert | M3×5×4 | 1 pack | — | Amazon | ¥5 | [Taobao](https://item.taobao.com/item.htm?id=809241671998) |
| Servo extension cable | SCS 3-pin, 26 cm | 12 | $0.43 | [AliExpress](https://www.aliexpress.com/item/1005008074862037.html) | ¥3 | [Taobao](https://item.taobao.com/item.htm?id=616460581906) |
| Camera — wrist | H65V1, 720p, 2.4 mm, 2 m cable | 2 | ~$17 | Amazon | ¥122 | [Taobao](https://item.taobao.com/item.htm?id=666278411821) |
| Bus servo controller | Waveshare Bus Servo Adapter A | 2 | $5.00 | [Waveshare](https://www.waveshare.com/bus-servo-adapter-a.htm) | ¥27 | [Tmall](https://detail.tmall.com/item.htm?id=738817173460) |
| USB Type-C cable | 1 m (arm → Pi 5) | 4 | — | — | ¥4.8 | [pinduoduo](https://mobile.yangkeduo.com/goods1.html?ps=fDPvH0kvgs) |
| 3D-printed parts | PLA/PETG/ABS, Bambu P2S | — | — | — | — | `/AlohaMini2/hardware/arms/stl/` |

---

## Leader Arms (×2)

| Item | Spec | Qty | Unit ($) | Buy (US) | Unit (¥) | Buy (CN) |
|---|---|----:|---:|---|---:|---|
| Servo — STS-3215 | ST-3215-C046, 7.4V, 1/147 gear | 14 | $15.97 | [Alibaba](https://www.alibaba.com/product-detail/Lerobot-360-Degree-Smart-Servo-for_1601563310522.html) | ¥110 | [Taobao](https://e.tb.cn/h.64H9u3maGWzIp5Q?tk=T5liexkG6Yz) |
| Heat-set insert | M3×5×4 | 1 pack | — | Amazon | ¥5 | [Taobao](https://item.taobao.com/item.htm?id=809241671998) |
| Bus servo controller | Waveshare | 2 | $12.47 | [Amazon](https://www.amazon.com/Waveshare-Integrates-Control-Circuit-Supports/dp/B0CTMM4LWK/) | ¥27 | [Tmall](https://detail.tmall.com/item.htm?id=738817173460) |
| Power supply 5V | DC 5V AC adapter | 1 | $12.99 | [Amazon](https://www.amazon.com/Facmogu-Switching-Transformer-Compatible-5-5x2-1mm/dp/B087LY41PV/) | — | — |
| USB Type-C cable | 1 m (arm → PC) | 2 | $7.19 | [Amazon](https://www.amazon.com/Charging-etguuds-Charger-Braided-Compatible/dp/B0B8NWLLW2/) | ¥20 | [Tmall](https://detail.tmall.com/item.htm?id=754024805047) |
| DC splitter cable | 1-to-2, 70 cm | 1 | — | — | ¥6.5 | [Taobao](https://e.tb.cn/h.ivLJNFtMOZ50iFx?tk=GN8V5ki58UN) |
| 3D-printed parts | PLA/PETG/ABS, Bambu P2S | — | — | — | — | `/AlohaMini2/hardware/arms/stl/` |

---

## Fasteners & Consumables

| Item | Spec | Qty | Unit ($) | Buy (US) | Unit (¥) | Buy (CN) |
|---|---|----:|---:|---|---:|---|
| Heat-set insert M3 | M3×5×4 mm, 50-pack | 1 pack | ~$0.30 | Amazon | ¥2.2 | — |
| Hex socket screw M3×10 | 100-pack, blue thread-lock | 3 packs | ~$1.20 | — | ¥8.5 | — |
| Hex socket screw M3×18 | 50-pack | 1 pack | ~$0.65 | — | ¥4.72 | — |
| Epoxy adhesive | Loctite E-120HP 50 mL | 1 | ~$10 | Amazon | ¥74.9 | — |

---

## Total Estimate

| | CNY | USD |
|--|-----|-----|
| Mobile base | ¥2,475 | ~$344 |
| Follower arms | ¥3,320 | ~$461 |
| Leader arms | ¥1,646 | ~$277 |
| Fasteners & consumables | ¥107 | ~$15 |
| **Total (self-print)** | **¥7,548** | **~$1,097** |

> Filament cost (~5 kg) not included above

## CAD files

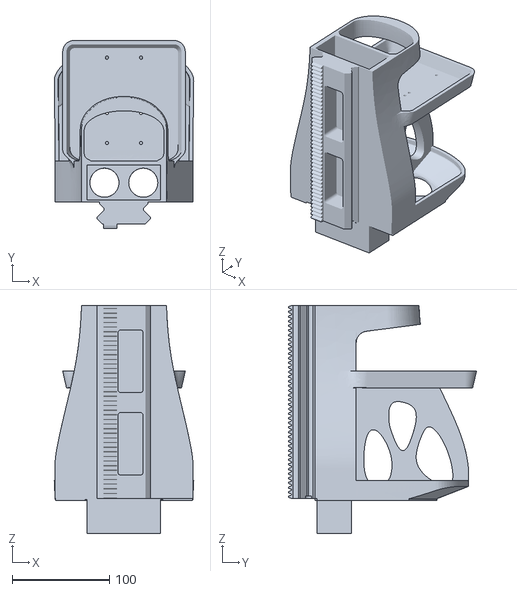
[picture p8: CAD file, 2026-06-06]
AlohaMini1/hardware/mobile_base/stl/O_Main_Assembly_Post4.stl
143.8 x 193.8 x 235.0

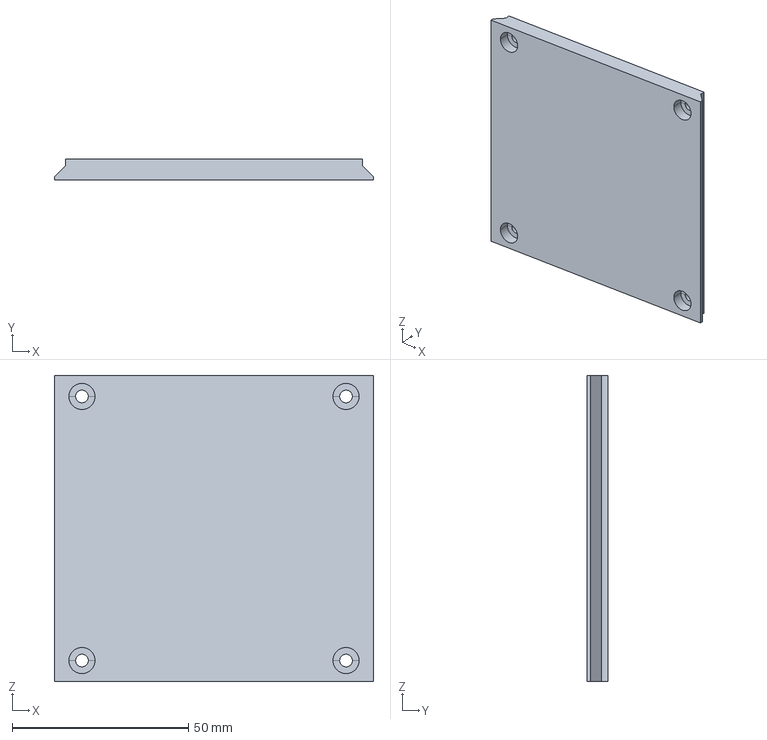
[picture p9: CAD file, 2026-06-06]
AlohaMini2/hardware/mobile_base2/stp/OB_Main_Monitor_Connector.stp
90.6 x 6.00 x 87.0 mm

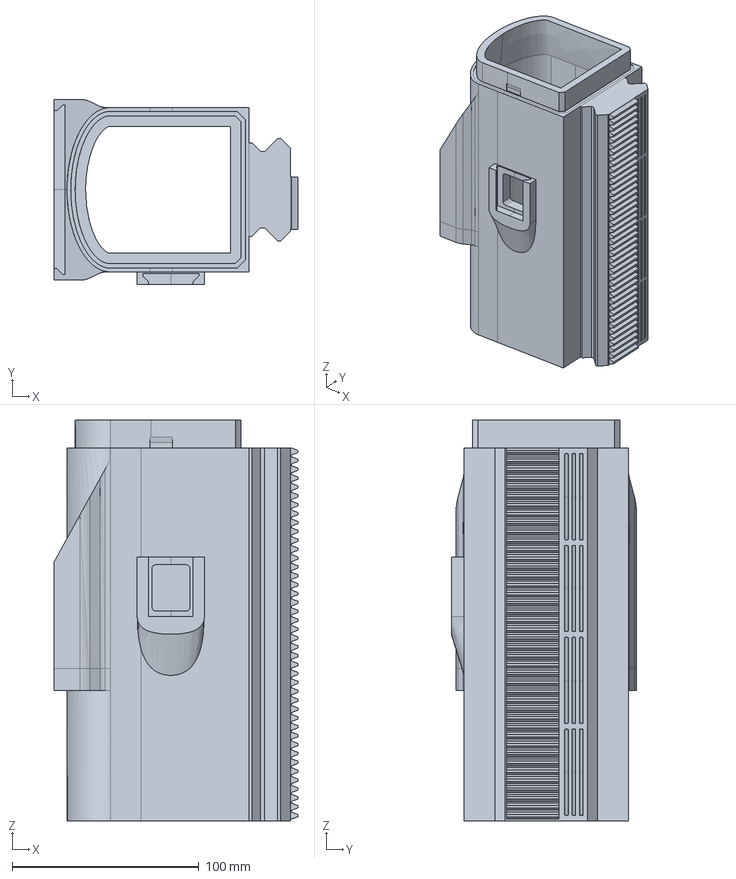
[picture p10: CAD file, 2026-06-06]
AlohaMini2/hardware/mobile_base2/stp/OB_Main_Assembly_Post1.stp
130.7 x 99.4 x 215.0 mm

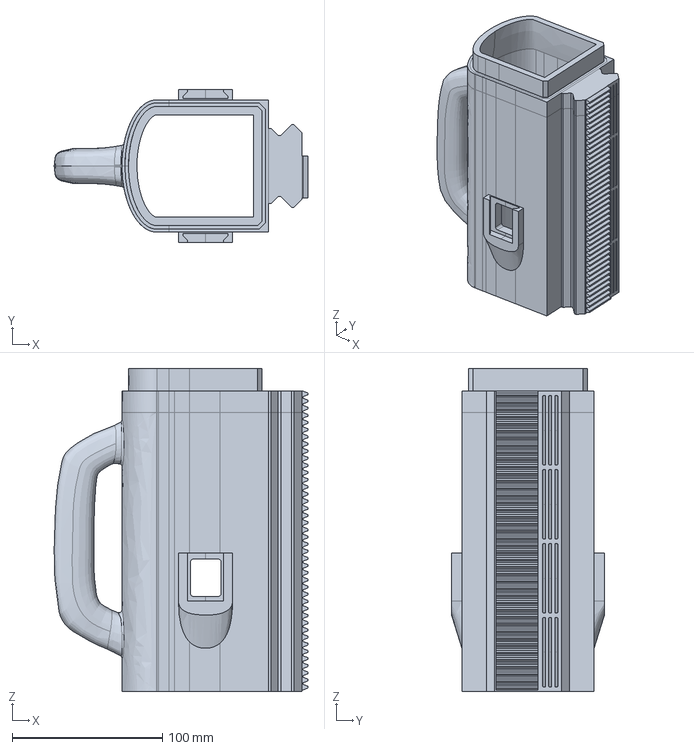
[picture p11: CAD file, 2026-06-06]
AlohaMini2/hardware/mobile_base2/stp/OB_Main_Assembly_Post2.stp
168.9 x 101.8 x 215.0 mm

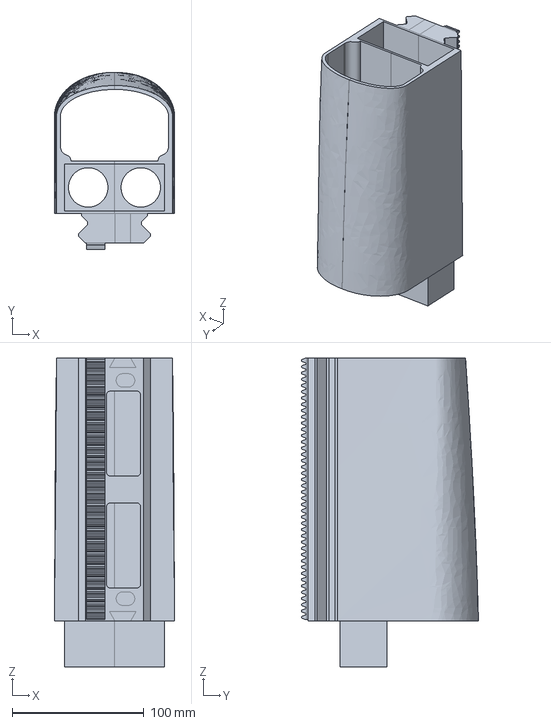
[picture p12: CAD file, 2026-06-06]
AlohaMini1/hardware/mobile_base/step/O_Main_Assembly_Post3.stp
91.5 x 134.6 x 235.0 mm

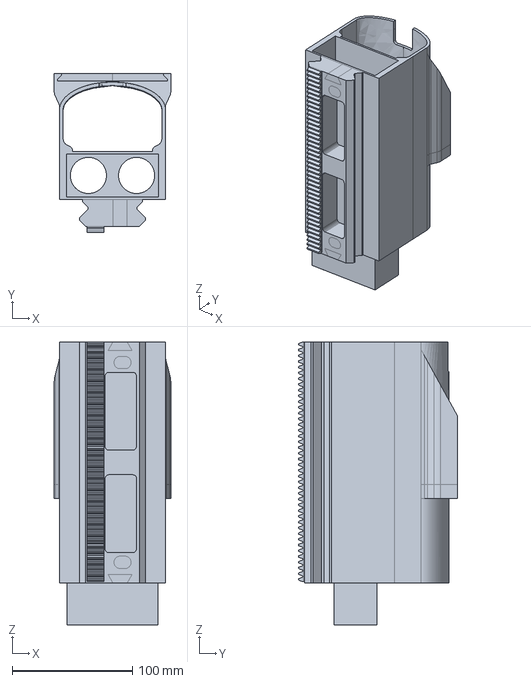
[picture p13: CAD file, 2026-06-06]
AlohaMini1/hardware/mobile_base/step/O_Main_Assembly_Post1.stp
97.0 x 131.7 x 235.0 mm

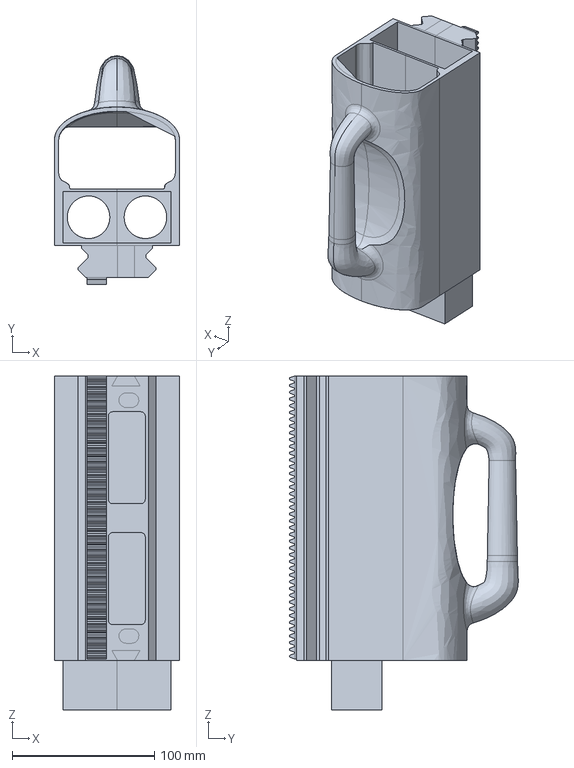
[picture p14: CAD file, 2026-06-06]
AlohaMini1/hardware/mobile_base/step/O_Main_Assembly_Post2.stp
88.1 x 160.9 x 235.0 mm

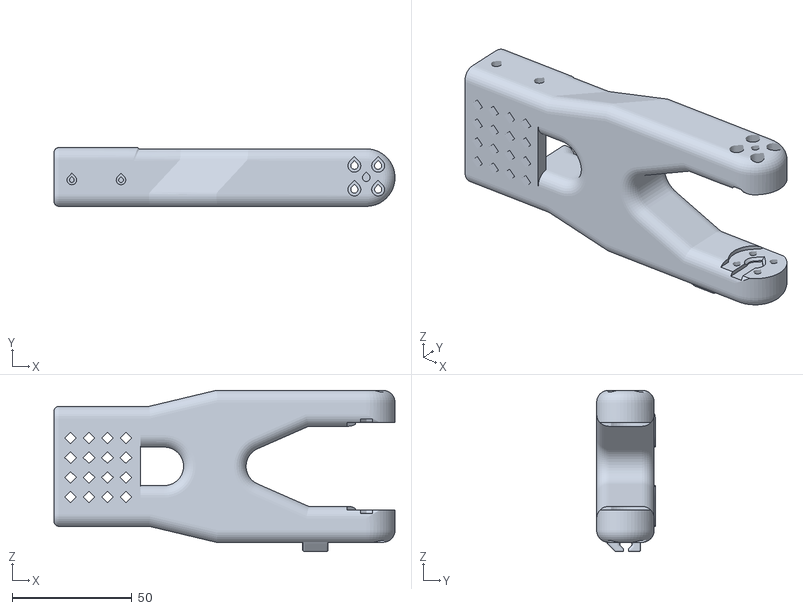
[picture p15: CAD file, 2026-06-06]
AlohaMini1/hardware/arms/stl/D_Upper_arm_SO101.stl
142.1 x 24.5 x 67.3

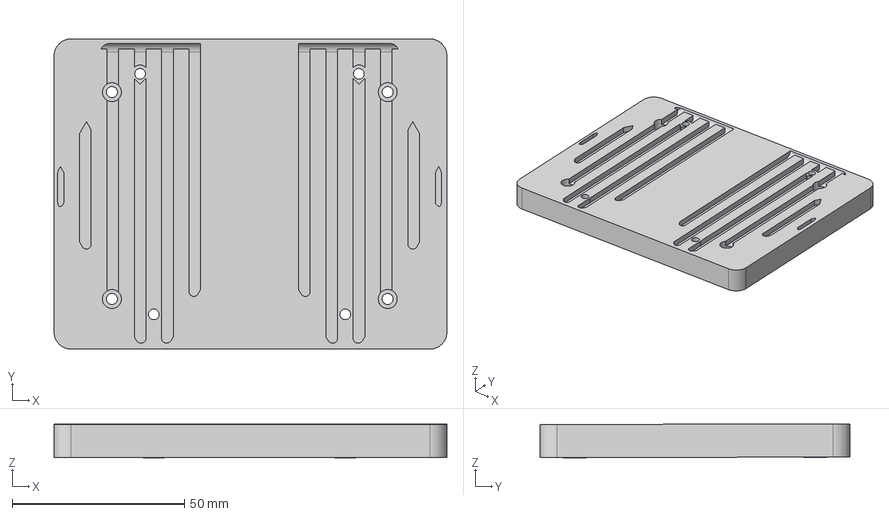
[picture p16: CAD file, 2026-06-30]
AlohaMini1/hardware/mobile_base/step/OB_T_Connector_So101_Adaptor.step
114.0 x 90.0 x 9.86 mm

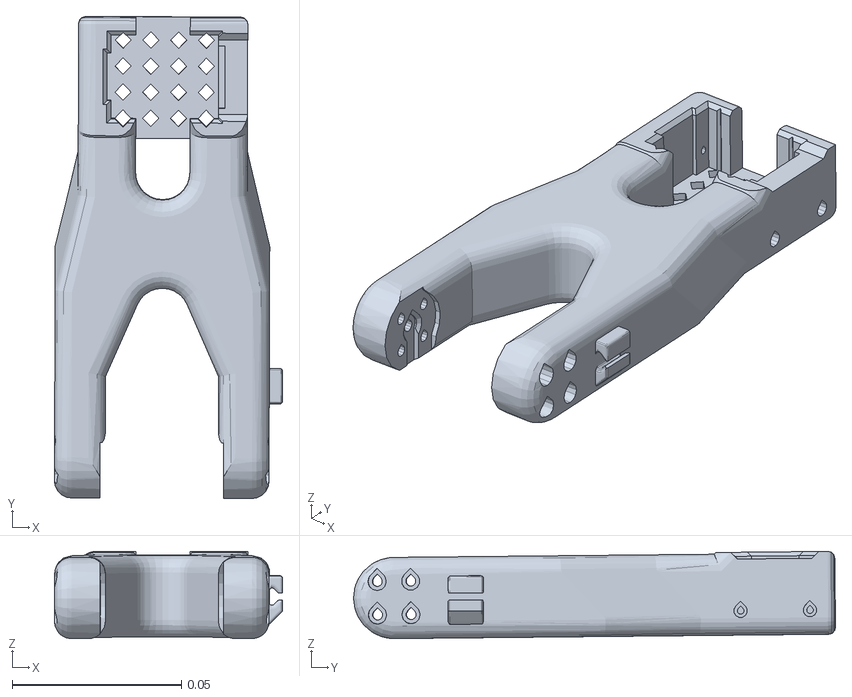
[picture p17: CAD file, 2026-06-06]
AlohaMini1/simulation/src/Aloha/meshes/right_link2.STL
0.0674 x 0.142 x 0.0258

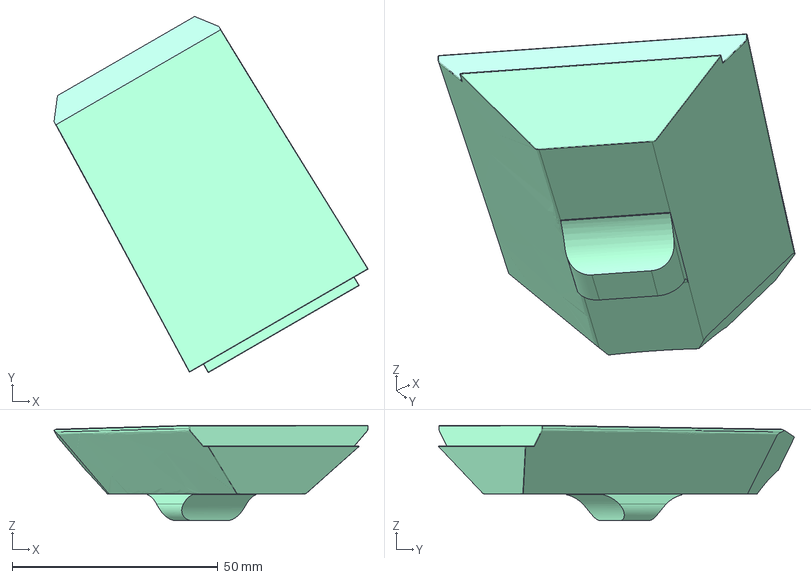
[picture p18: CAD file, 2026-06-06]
AlohaMini2/hardware/mobile_base2/stp/OB_Chassis_Locking_Wedge.stp
76.3 x 86.6 x 23.2 mm

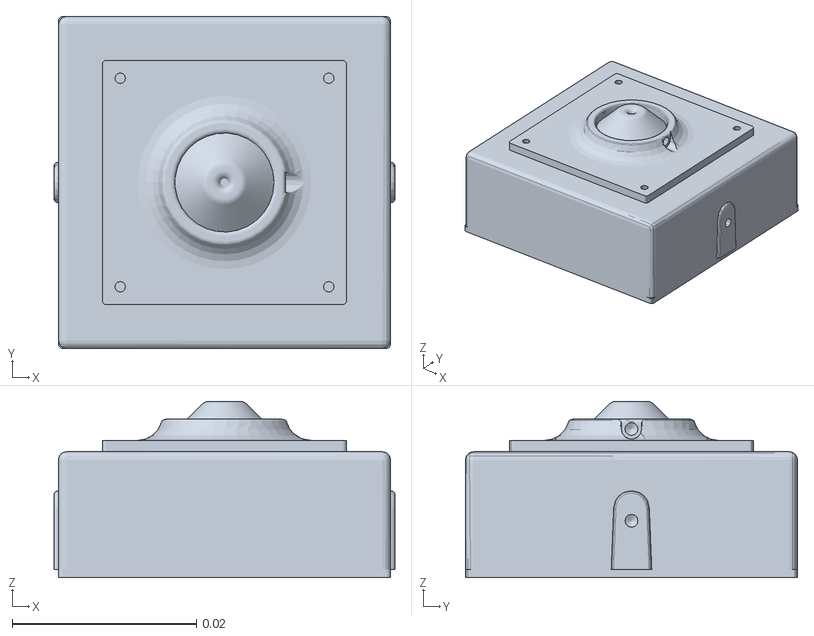
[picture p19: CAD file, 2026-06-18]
AlohaMini2/urdf/alohamini2/alohamini2_meshes/chest_camera.STL
0.037 x 0.036 x 0.0191

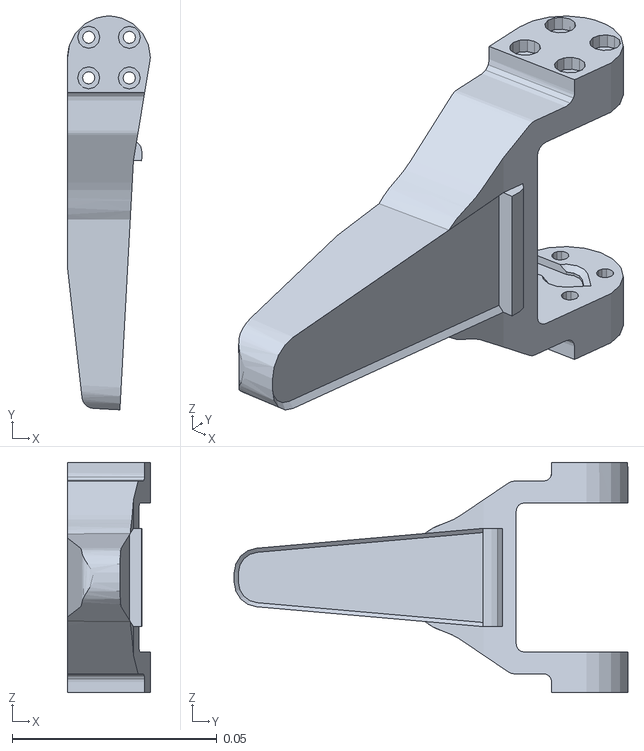
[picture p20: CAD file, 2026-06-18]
AlohaMini2/urdf/alohamini2pro/alohamini2pro_meshes/right_Moving_Jaw.STL
0.0202 x 0.0961 x 0.0561

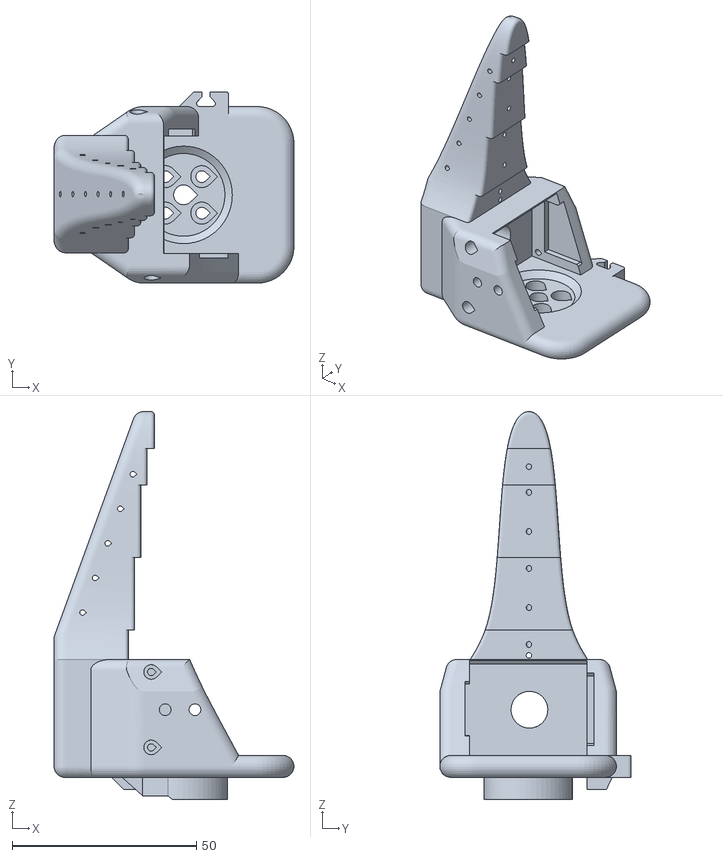
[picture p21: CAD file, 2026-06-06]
AlohaMini1/hardware/arms/stl/F_Follower_Wrist_Roll_Follower_SO101.stl
65.2 x 52.0 x 105.4

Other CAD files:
AlohaMini1/hardware/mobile_base/step/Monitor_Enclosure.step
AlohaMini1/hardware/mobile_base/stl/OB_Chassis_Wheel_Guard.stl
AlohaMini1/simulation/src/Aloha/meshes/right_link5.STL
AlohaMini1/hardware/arms/stl/D_Base_SO101_Lekiwi.stl
AlohaMini1/hardware/arms/stl/D_Base_motor_holder_SO101.stl
AlohaMini1/hardware/arms/stl/D_Motor_holder_SO101_Base.stl
AlohaMini1/hardware/arms/stl/D_Motor_holder_SO101_Wrist.stl
AlohaMini1/hardware/arms/stl/D_Rotation_Pitch_SO101.stl
AlohaMini1/hardware/arms/stl/D_Seeedstudio_Mounting_Plate_SO101.stl
AlohaMini1/hardware/arms/stl/D_Under_arm_SO101.stl
AlohaMini1/hardware/arms/stl/D_WaveShare_Mounting_Plate_SO101.stl
AlohaMini1/hardware/arms/stl/D_Wrist_Roll_Pitch_SO101.stl
AlohaMini1/hardware/arms/stl/D_Wrist_Roll_SO101.stl
AlohaMini1/hardware/arms/stl/F_Follower_Moving_Jaw_SO101.stl
AlohaMini1/hardware/arms/stl/F_Follower_SO-ARM101_camera_wrist_mount.stl
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

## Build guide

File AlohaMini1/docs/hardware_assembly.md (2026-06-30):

# Assembly

## Mobile Base Assembly

1. Using the servo software ([FD Debug Tool v1.9.8.3](https://www.feetechrc.com/Data/feetechrc/upload/file/20240622/FD1.9.8.3.zip)), assign ID numbers 8, 9, 10, and 11 to the servos respectively.

   **How to adjust:**
   
   To assign ID numbers to the servos using the FD Debug Tool:
   
   - **Download and install** the FD Debug Tool from the link above
   - **Connect** the servo to your computer using the Waveshare Bus Servo Controller (via USB) 
   - **Launch** the FD Debug Tool software
   - **Select** the correct COM port and set the baud rate (typically 1000000 or as specified in your servo manual)
   - **Click** "Scan Servo" to detect the connected servo and its current ID
   - **Change the ID** by entering the desired number (8, 9, 10, or 11) in the ID field
   - **Click** "Write" or "Save" to update the servo's ID
   - **Disconnect** the servo and repeat the process for each remaining servo
   
   **Note:** Make sure to connect and configure only one servo at a time to avoid ID conflicts during the setup process.

1. Connect servos 8, 9, and 10 using the included 20cm servo cables, and connect servos 10 and 11 using a 90cm servo cable.
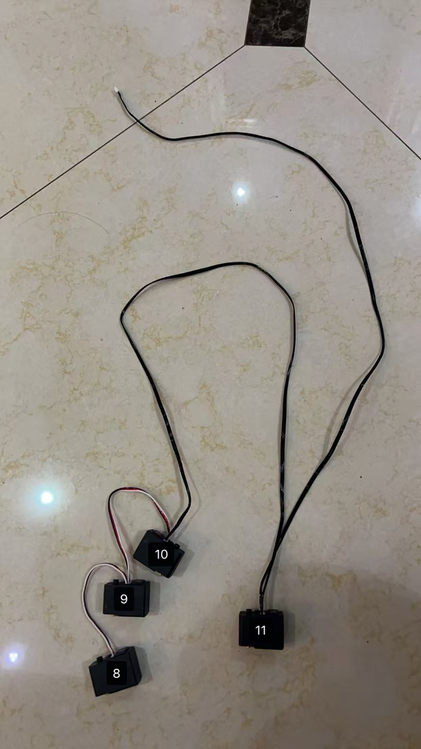
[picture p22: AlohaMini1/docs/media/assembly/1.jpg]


3. Install M3 heat-set inserts into the servo brackets using a soldering iron.
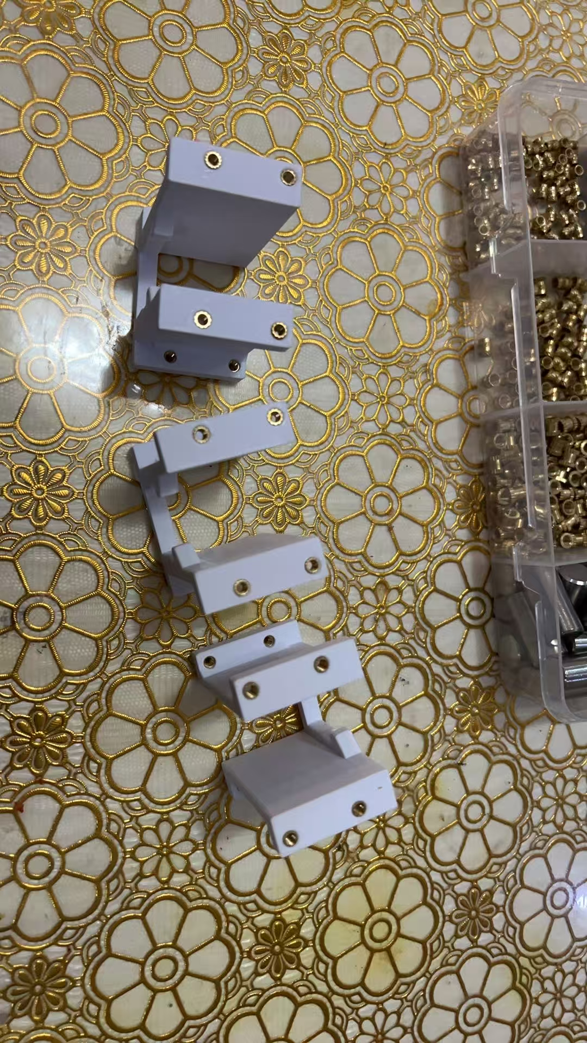
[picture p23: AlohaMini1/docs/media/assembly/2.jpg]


4. Secure the servos using the small screws included with the servos.
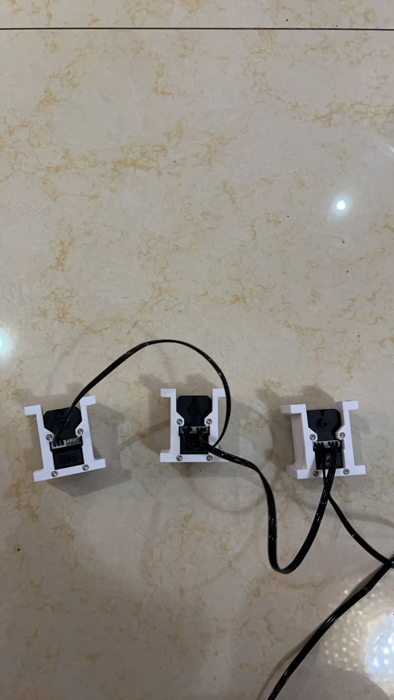
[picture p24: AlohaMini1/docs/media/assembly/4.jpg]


5. Install the wheel axle connectors.
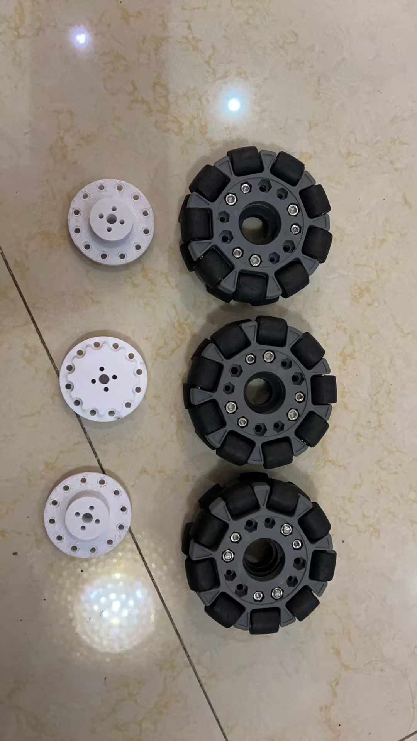
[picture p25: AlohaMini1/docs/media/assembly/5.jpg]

If the connector doesn't fit, sand it down for a better fit.
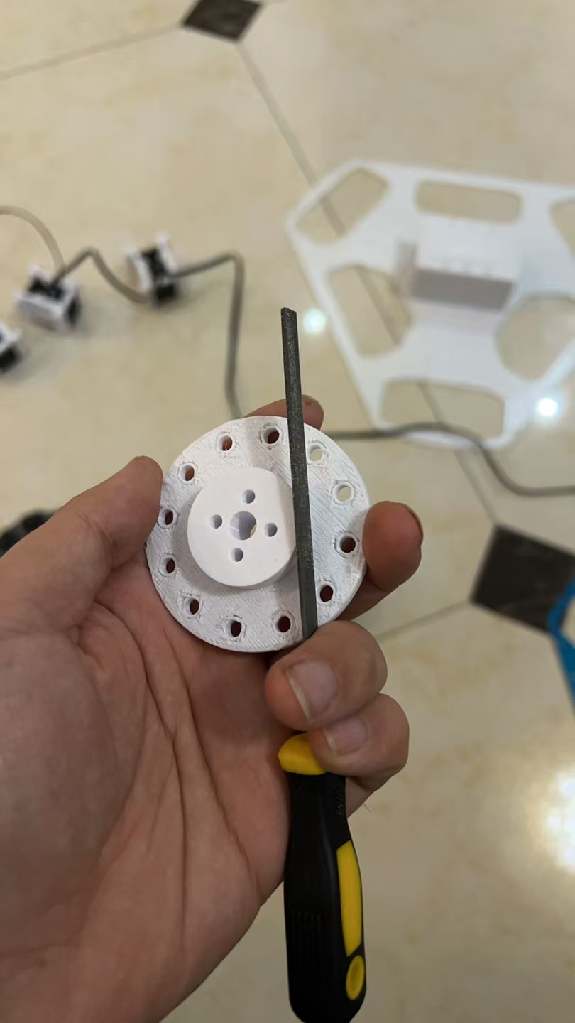
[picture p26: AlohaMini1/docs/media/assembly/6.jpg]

Connector installation complete (if it's loose, tighten with screws or use epoxy resin for bonding; no additional treatment needed if it's tight enough).
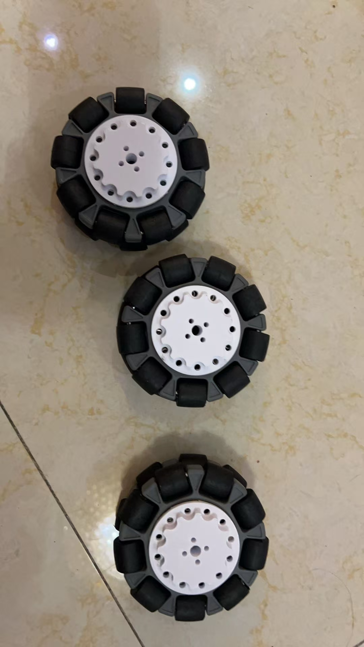
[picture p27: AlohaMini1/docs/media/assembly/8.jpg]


6. Mount the servos to the chassis plate.
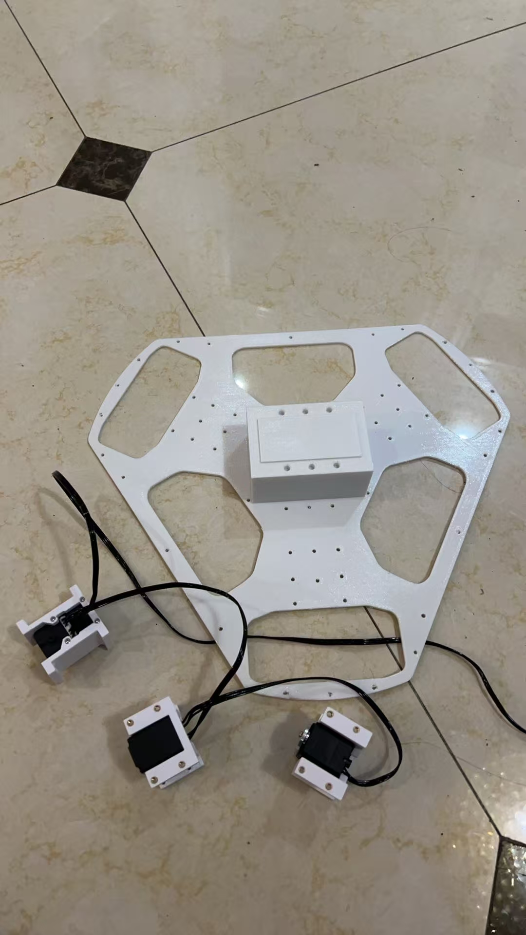
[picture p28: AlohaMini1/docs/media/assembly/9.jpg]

Follow the servo order as shown in the image.
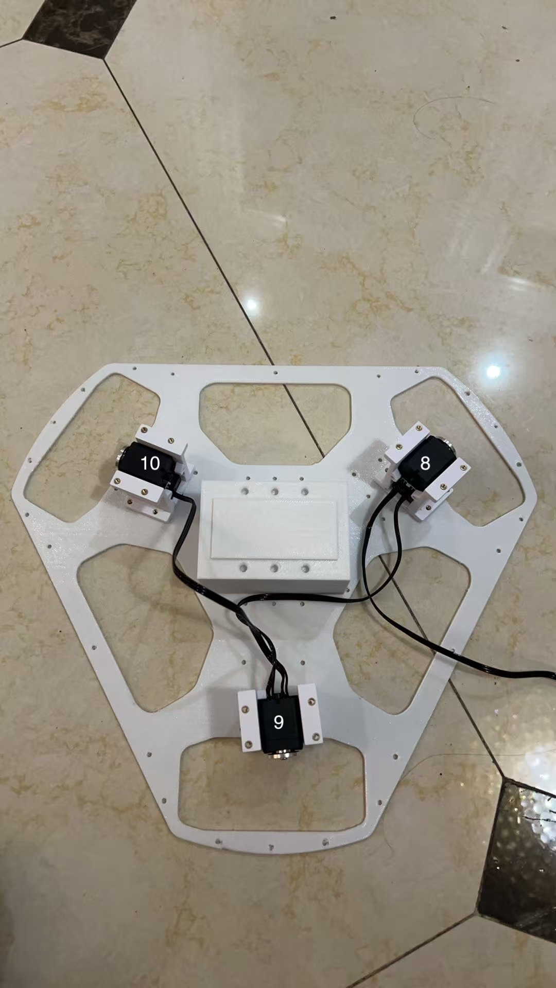
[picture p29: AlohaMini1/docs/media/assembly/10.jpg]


7. Secure the servos to the chassis plate using M3x14 screws.
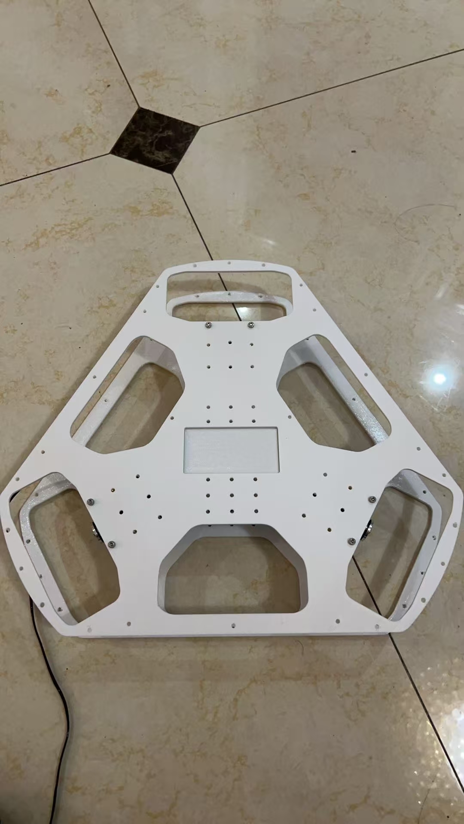
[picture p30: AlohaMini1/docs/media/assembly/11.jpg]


8. Attach the omni wheels to the servo connector using M3x18 screws.
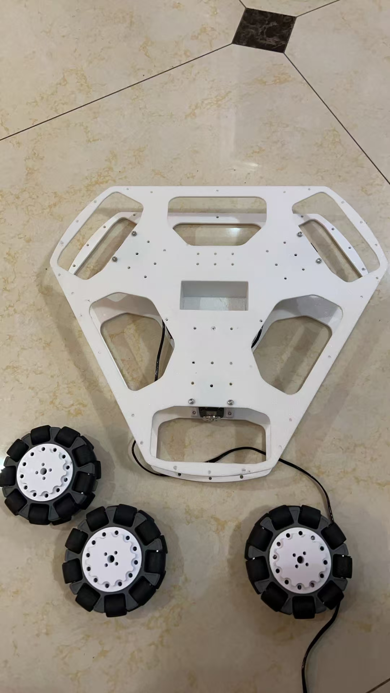
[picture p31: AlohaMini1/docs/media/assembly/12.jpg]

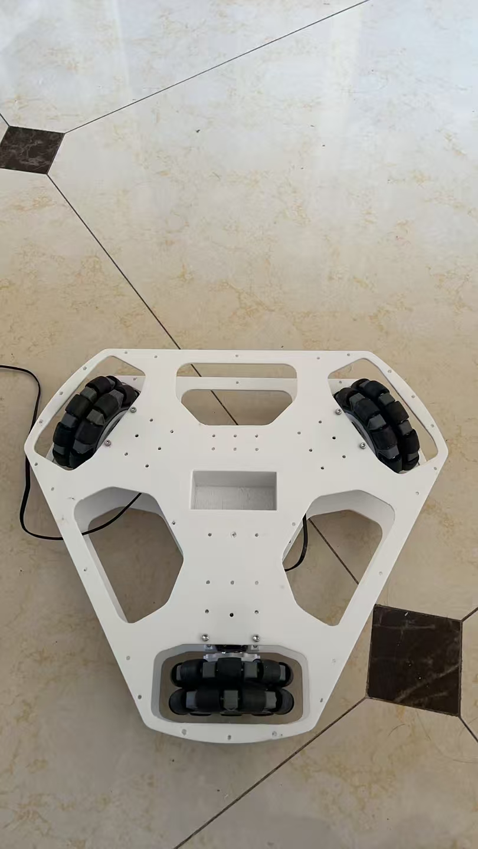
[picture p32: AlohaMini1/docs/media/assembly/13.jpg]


9.  (optional)Install the chassis bearings.
Insert the bearings (12x18x4) into the dowel pin and shaft sleeves.
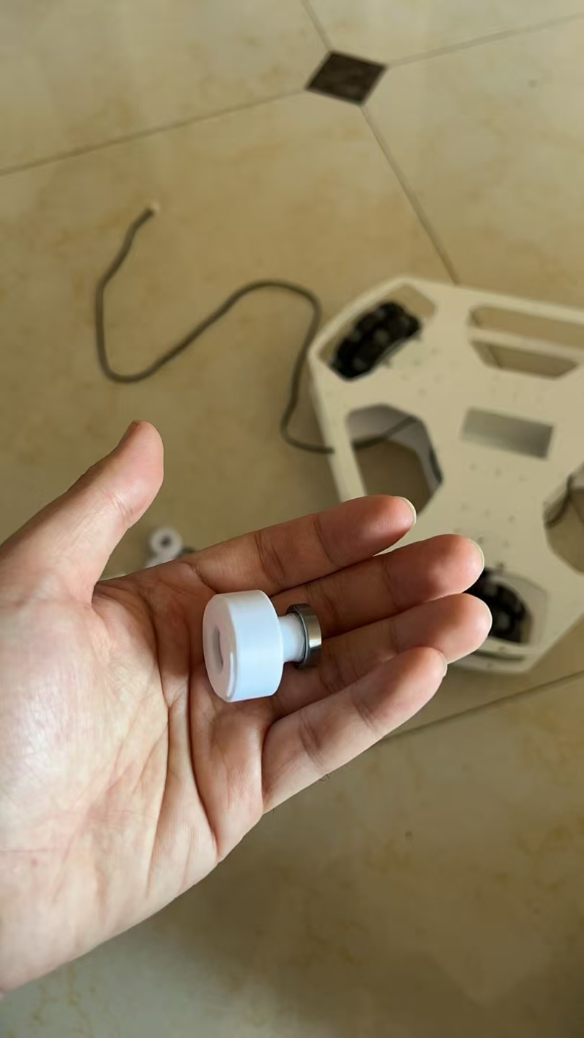
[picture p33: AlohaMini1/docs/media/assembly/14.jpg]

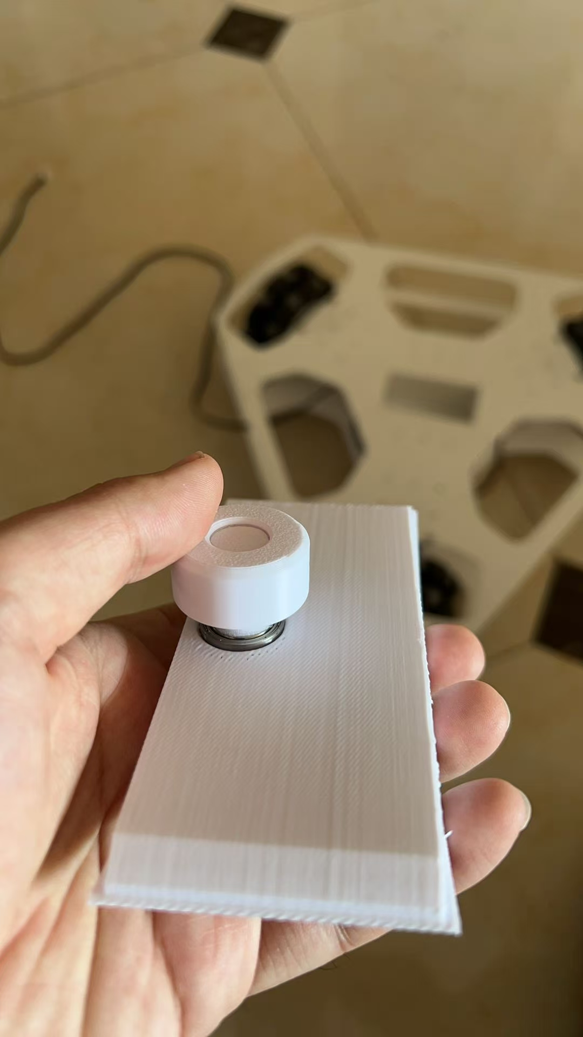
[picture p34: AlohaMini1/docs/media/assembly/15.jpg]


Install the M4 heat-set inserts into the Chassis_Bearing_Cover, then fasten it using M4x12 screws.
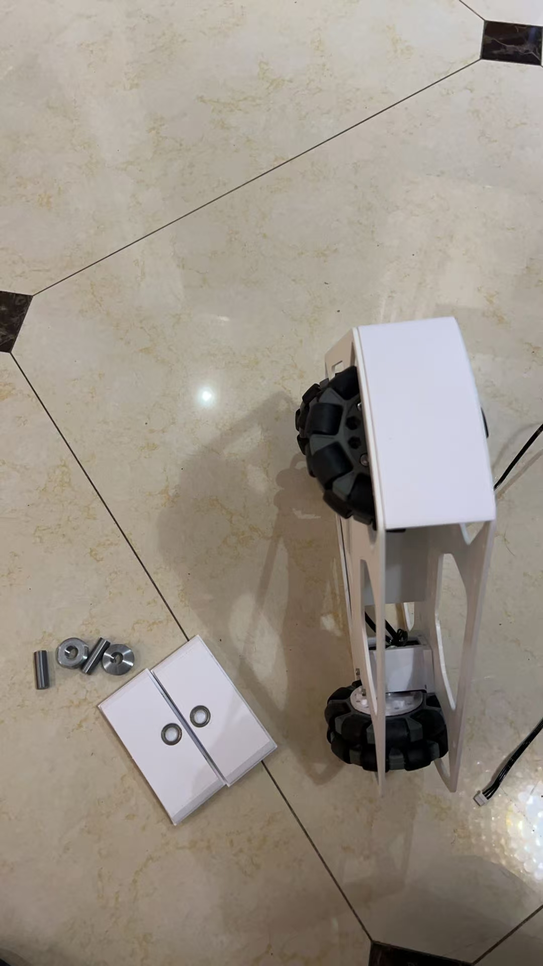
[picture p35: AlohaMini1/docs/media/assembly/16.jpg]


10. Install M3 heat-set inserts into the side plates.
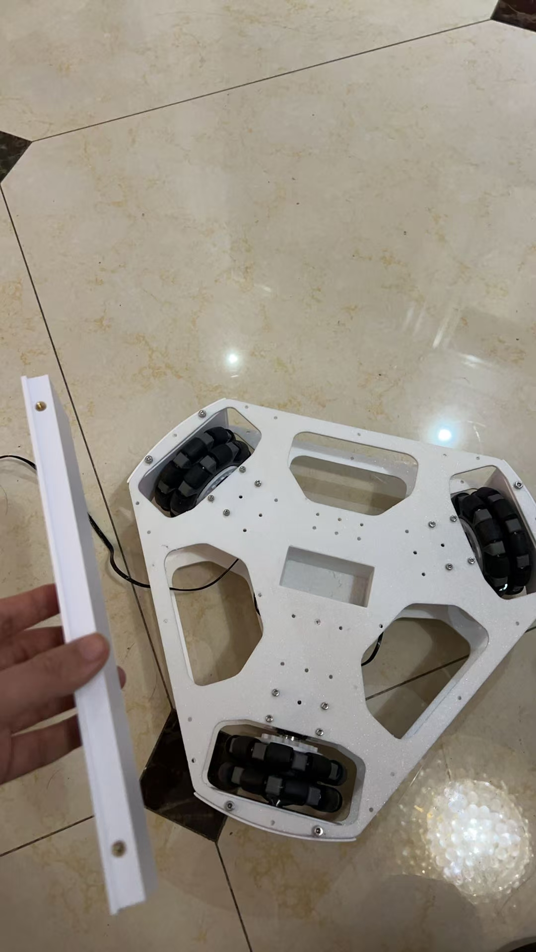
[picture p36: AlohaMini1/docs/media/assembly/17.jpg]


11. Assemble the main posts like building blocks - there are 4 in total. Use epoxy resin or double-sided tape to bond the parts together.
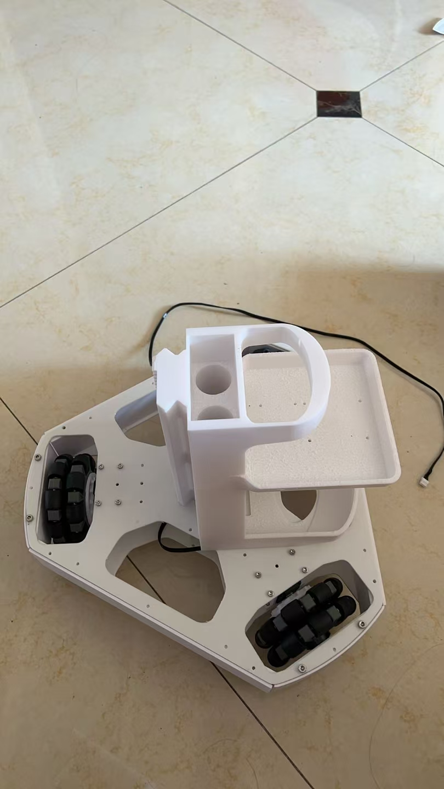
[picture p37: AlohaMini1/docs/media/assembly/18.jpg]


12. Install the lift axis. Prepare the materials according to the BOM list.
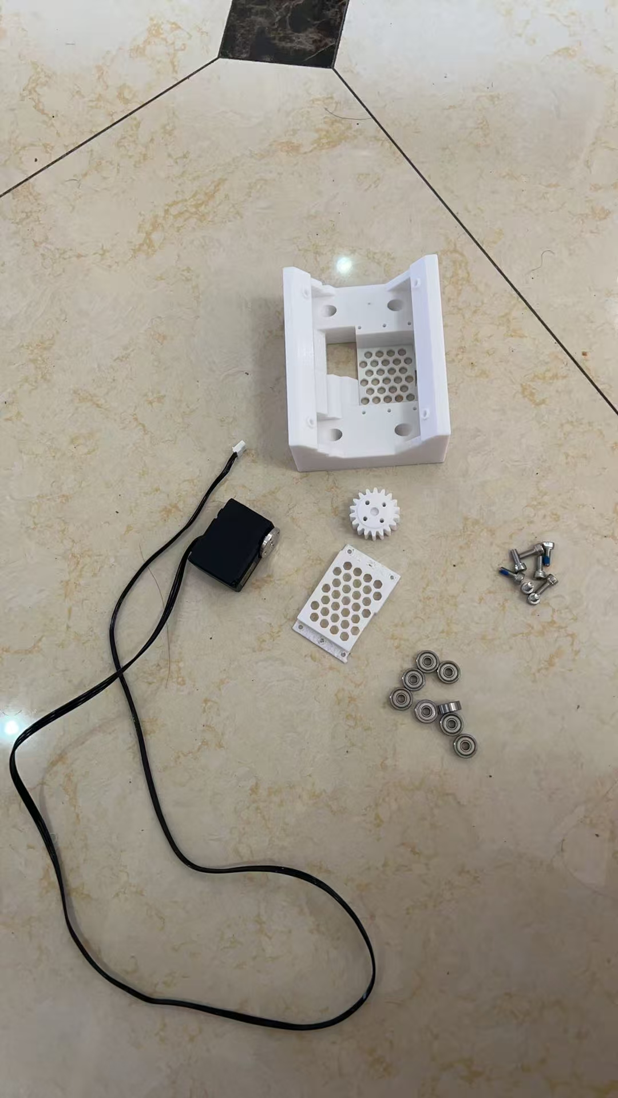
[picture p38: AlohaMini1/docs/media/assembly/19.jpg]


13. Secure the gear using the screws included with the servo.
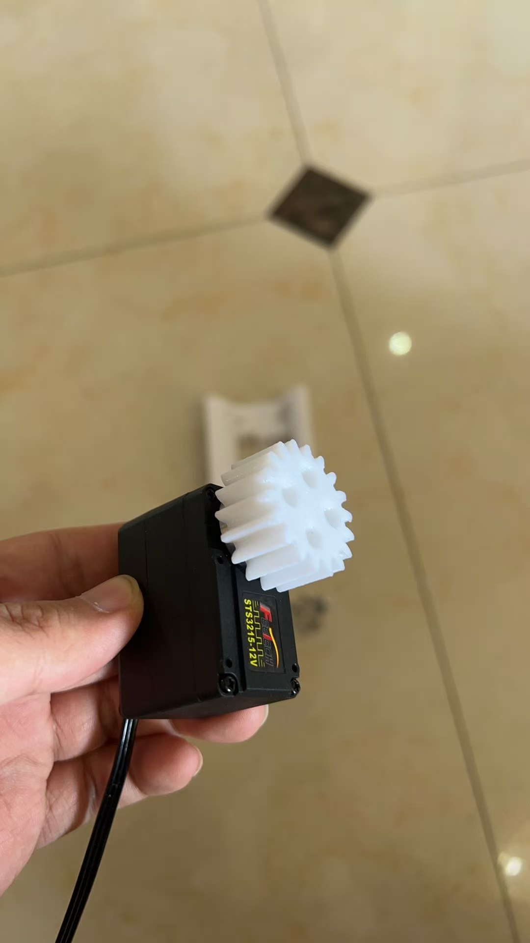
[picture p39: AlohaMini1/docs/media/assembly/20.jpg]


14. Insert the gear into the Axis_Servo_Mount.
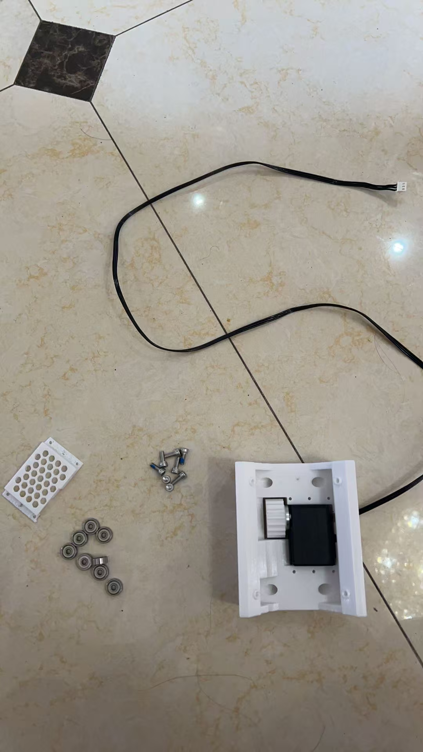
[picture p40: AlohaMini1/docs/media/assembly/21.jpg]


15. Secure the Axis_Bracket to the servo using the included M3x6 screws from the servo.
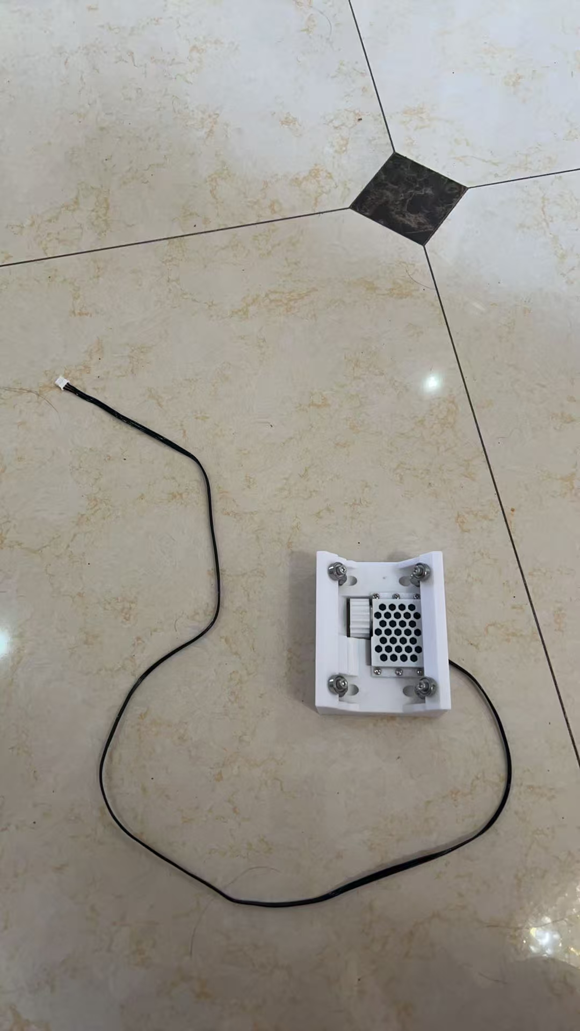
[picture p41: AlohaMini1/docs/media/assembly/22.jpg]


17. Install the T-bracket.
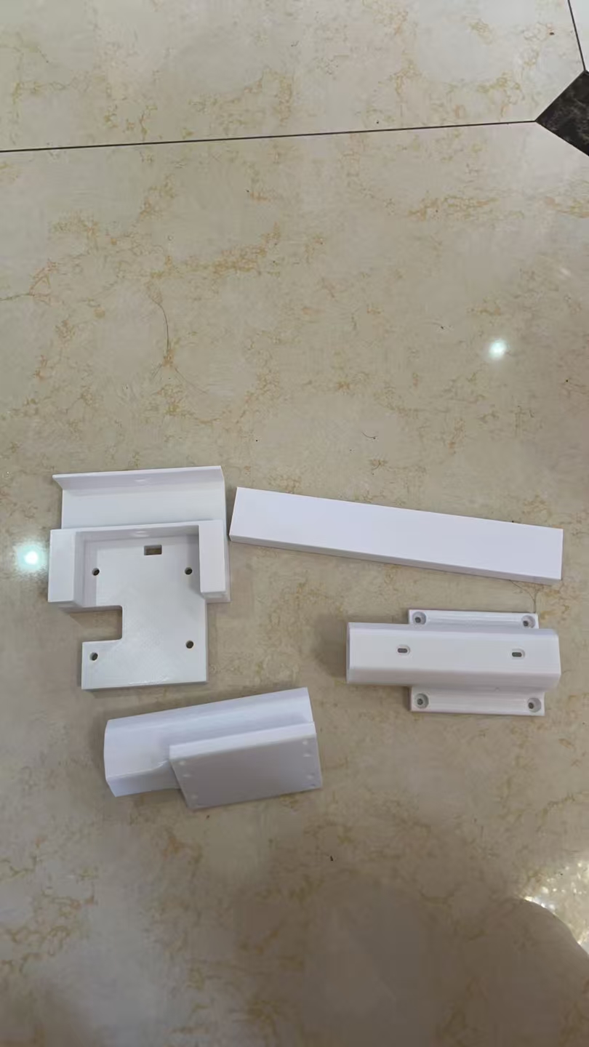
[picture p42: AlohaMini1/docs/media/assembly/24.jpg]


18. Secure it with epoxy resin.
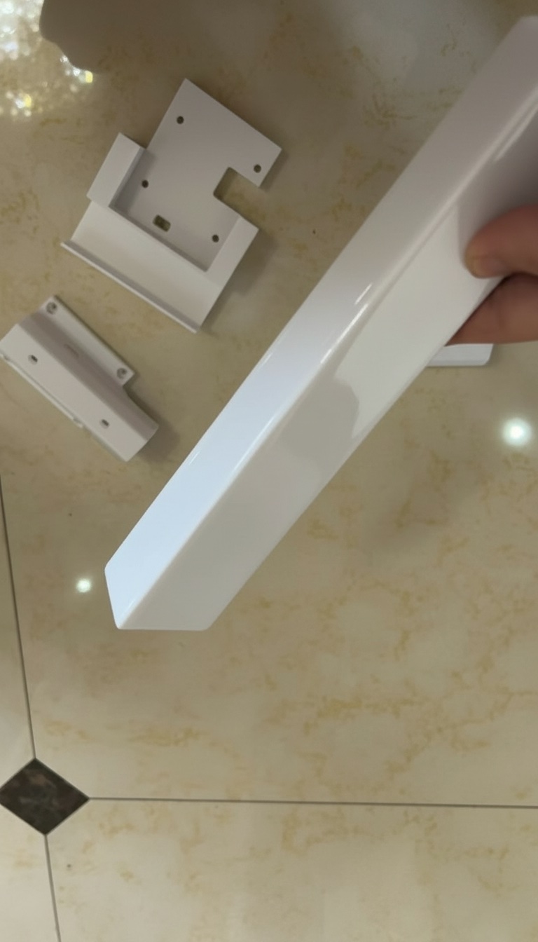
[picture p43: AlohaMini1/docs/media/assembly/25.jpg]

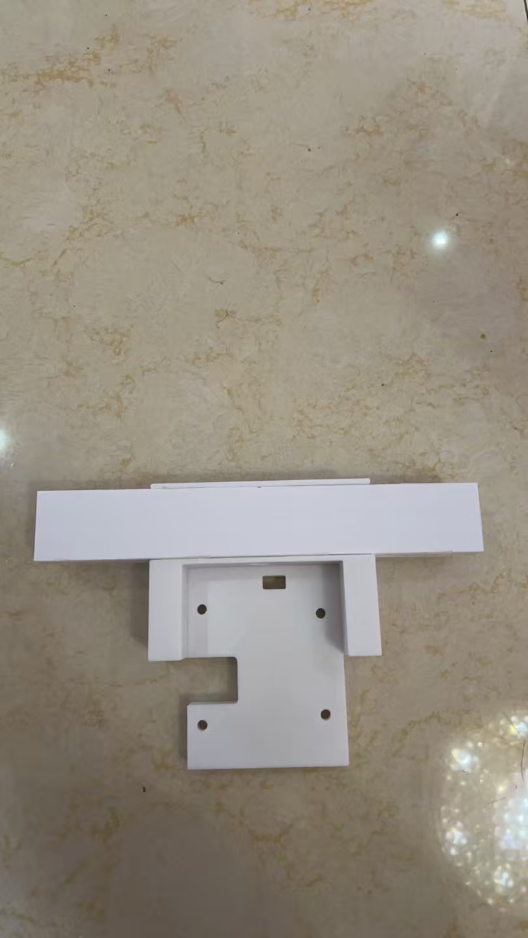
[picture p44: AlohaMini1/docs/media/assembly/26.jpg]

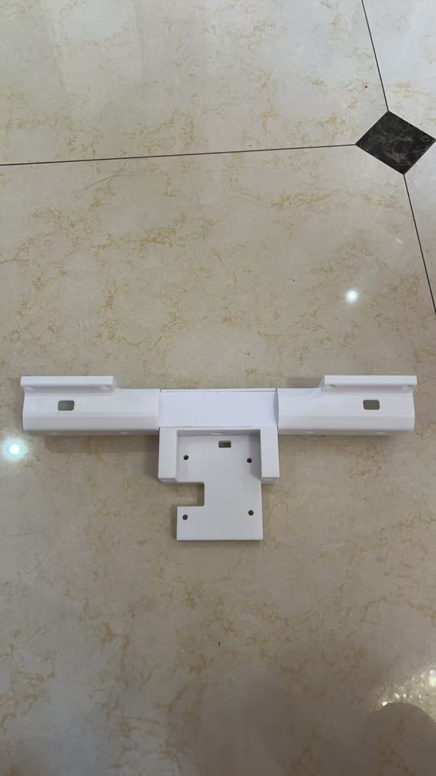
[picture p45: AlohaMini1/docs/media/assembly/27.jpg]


19. Slide the lift axis into the T-bracket.
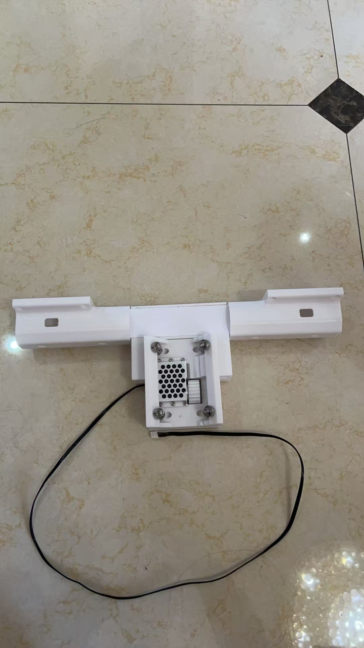
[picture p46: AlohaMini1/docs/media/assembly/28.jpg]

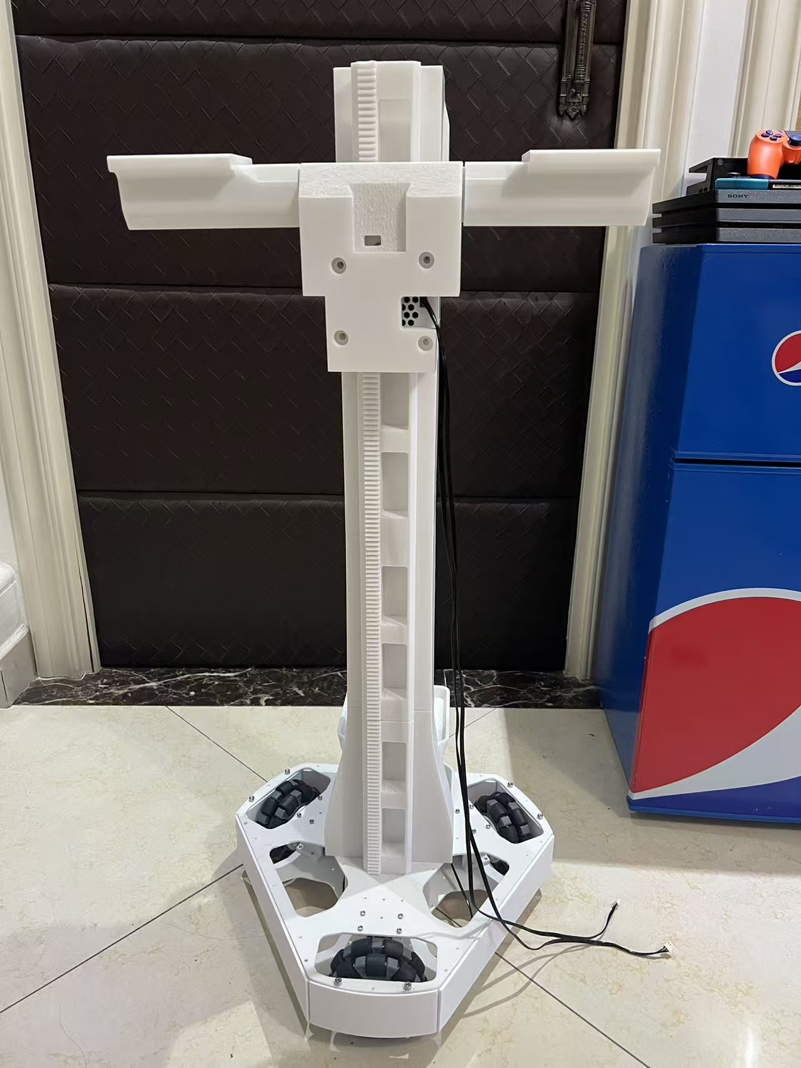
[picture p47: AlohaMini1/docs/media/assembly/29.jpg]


20. Install the Top and Back cameras.
Remove the two screws from the camera back cover.
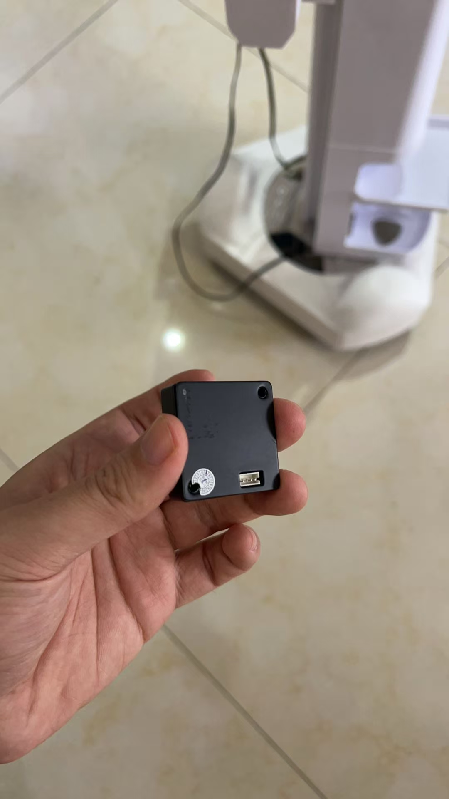
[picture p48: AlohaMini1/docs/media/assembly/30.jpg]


21. Reinstall the back cover using M2x12 screws, sandwiching the printed part in between.
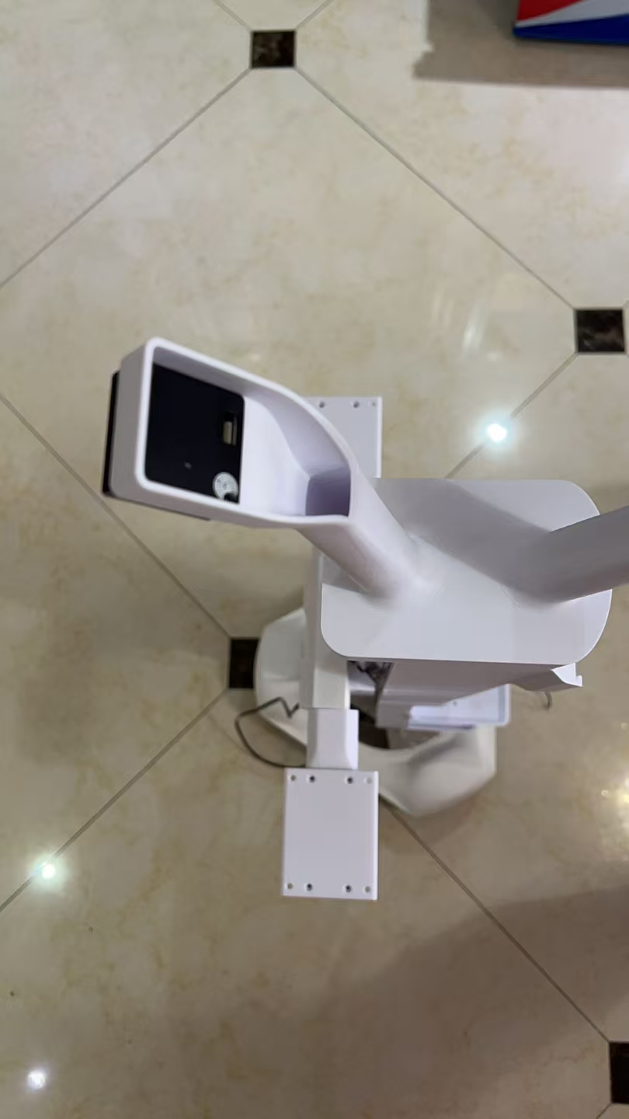
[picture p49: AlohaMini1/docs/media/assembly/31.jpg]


22. Route the camera cable through the internal channel of the printed part.
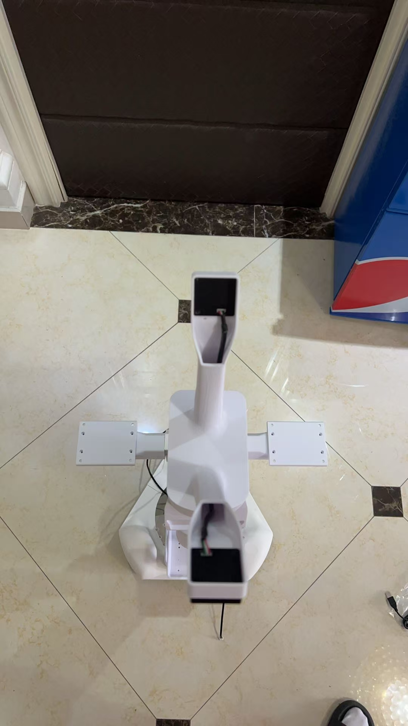
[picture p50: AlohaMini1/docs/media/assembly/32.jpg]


23. Secure the display to the printed part using the included M3 servo screws.
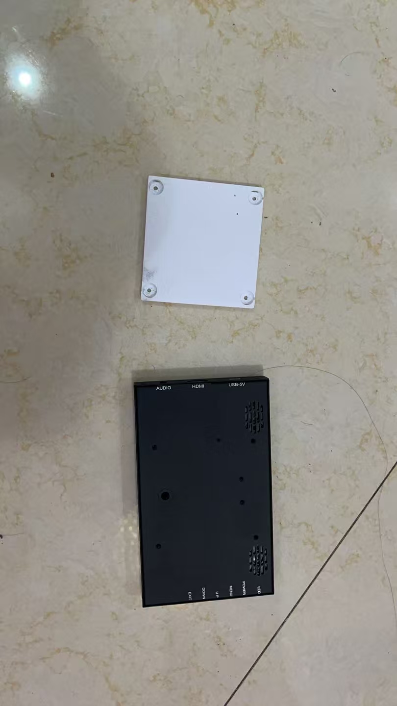
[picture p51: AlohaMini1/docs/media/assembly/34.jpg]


24. Slide the display into the rear slot of the main post.
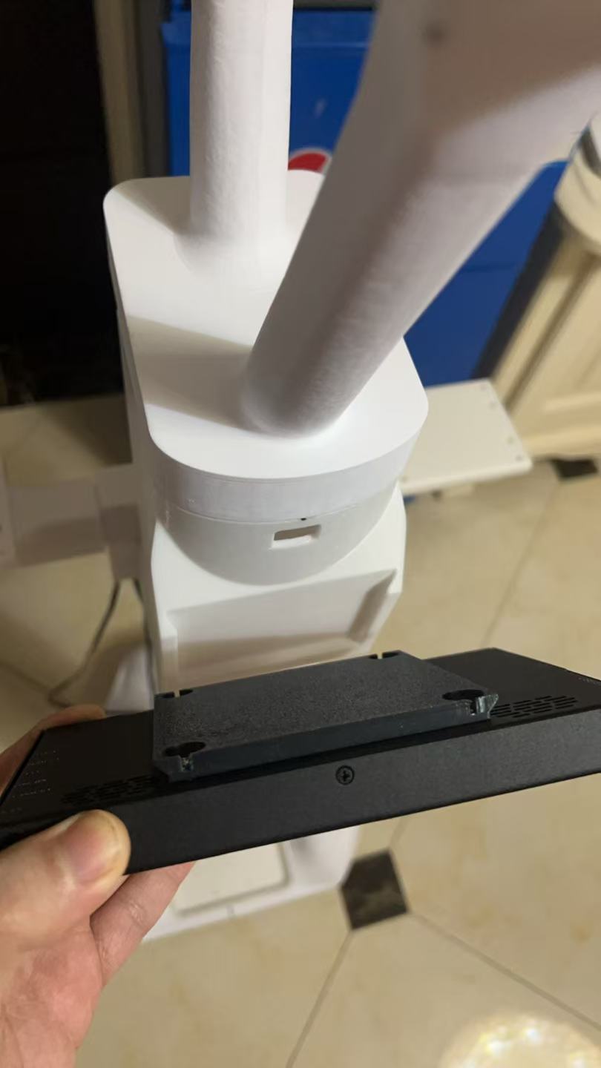
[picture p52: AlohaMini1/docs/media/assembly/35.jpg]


25. Install the Front camera using the same method as the Top camera.
Slide it into the slot. If there are any burrs on the printed part, file them down for a smooth fit.

26. Route the USB Type-C data cable and DC power cable through the hole on the rear side of the main post.
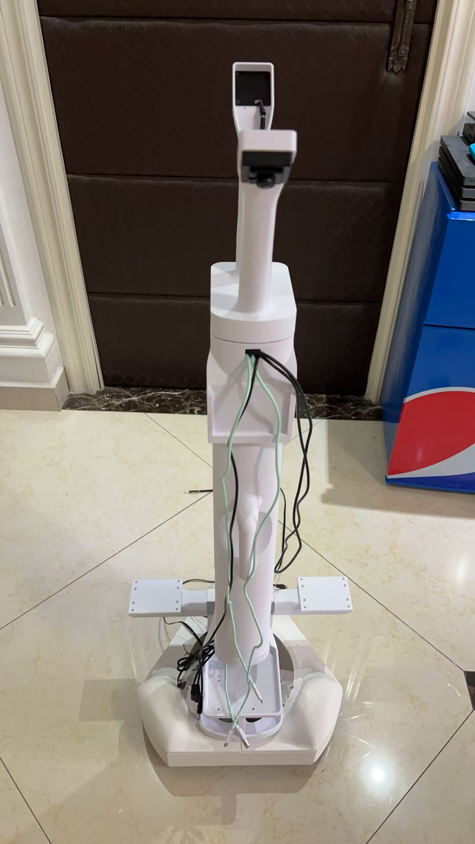
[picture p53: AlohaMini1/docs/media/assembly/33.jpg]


27. Mobile Base assembly complete!
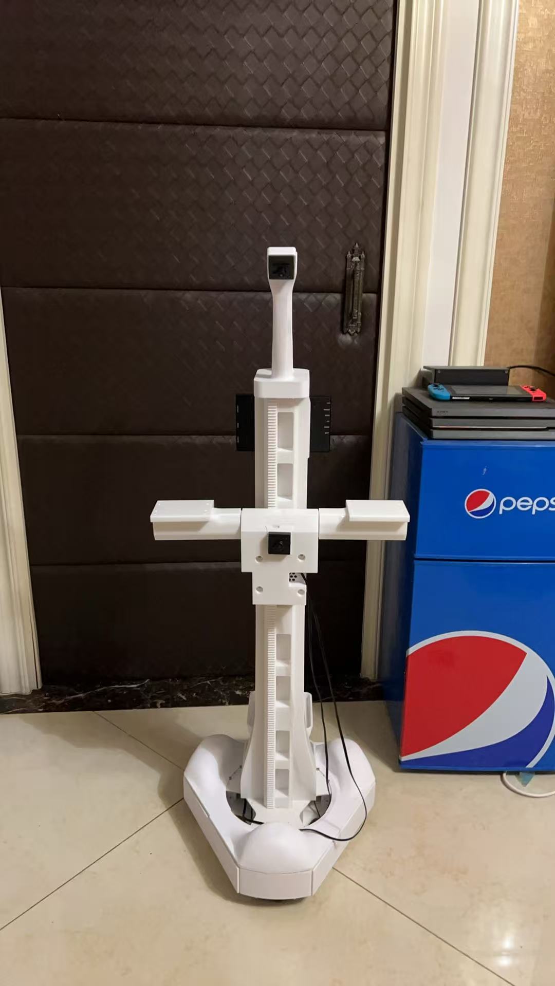
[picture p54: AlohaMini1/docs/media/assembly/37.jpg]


## Leader arms and Follower arms
For the assembly of Leader arms and Follower arms, please refer to the tutorial: [SO-101 Assembly Guide](https://huggingface.co/docs/lerobot/so101). 

## Follower arms and Mobile Base Assembly

1. Secure the robotic arm to both sides of the T-bracket using four M3x30 hex screws and four M3 nuts.
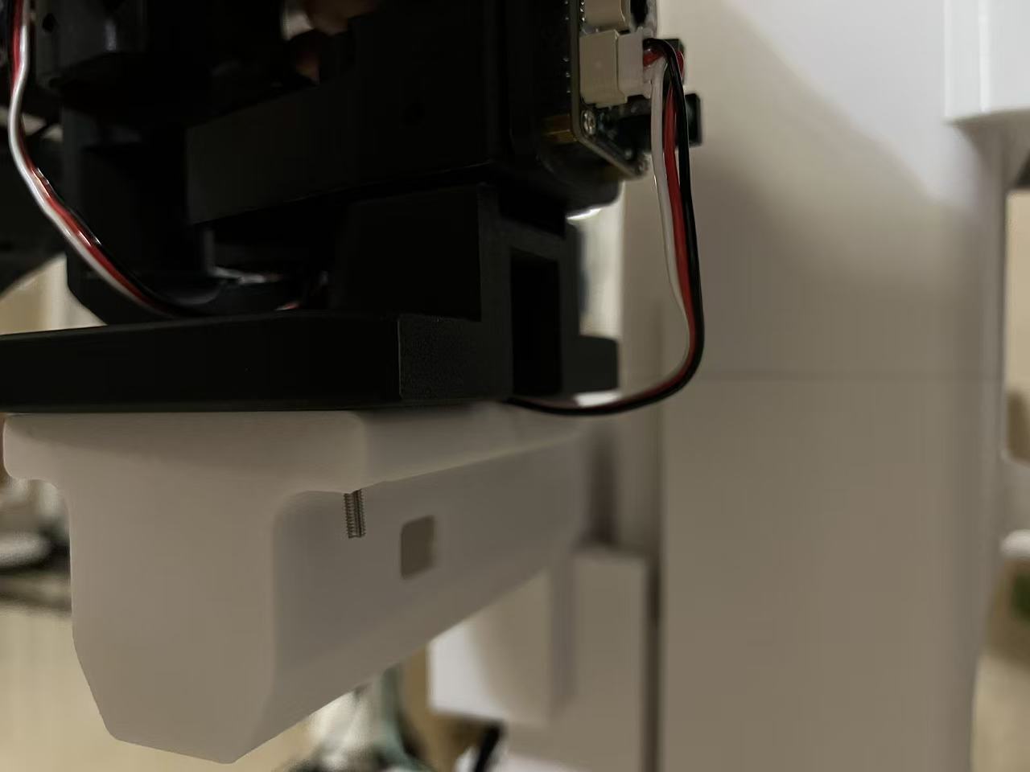
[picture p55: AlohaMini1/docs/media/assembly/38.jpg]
   

2. Connect the 90cm servo cable from servo #11 to the other port on the Waveshare controller board of the **left arm**.
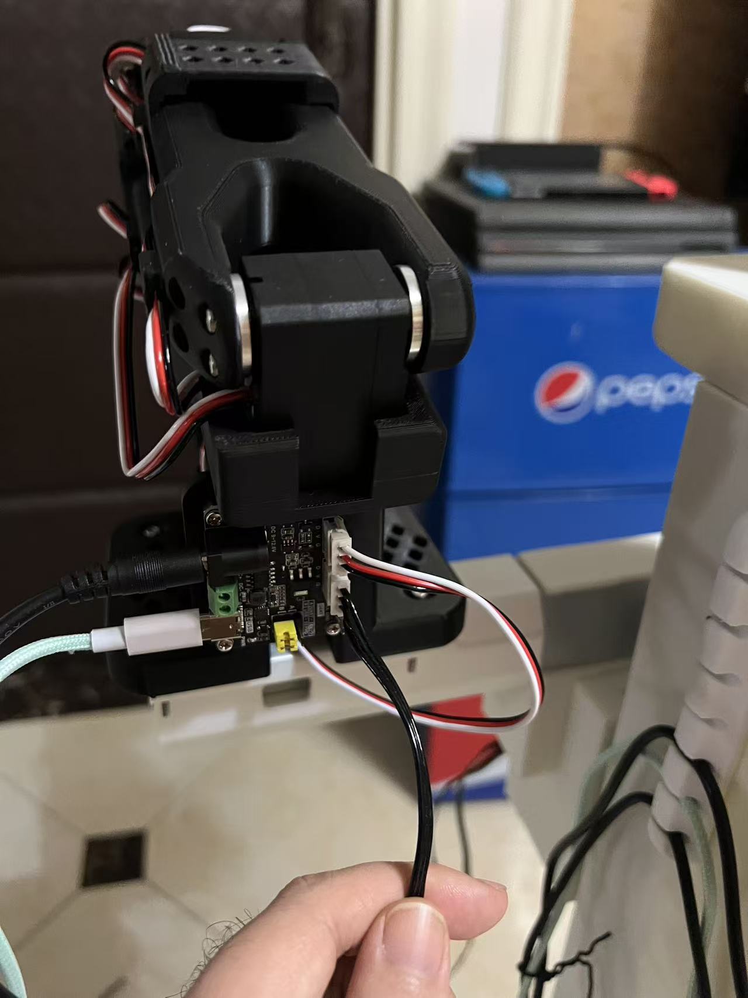
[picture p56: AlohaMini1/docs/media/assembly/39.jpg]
   

3. Attach the 12V to 5V step-down converter to the base and connect it to the Raspberry Pi.
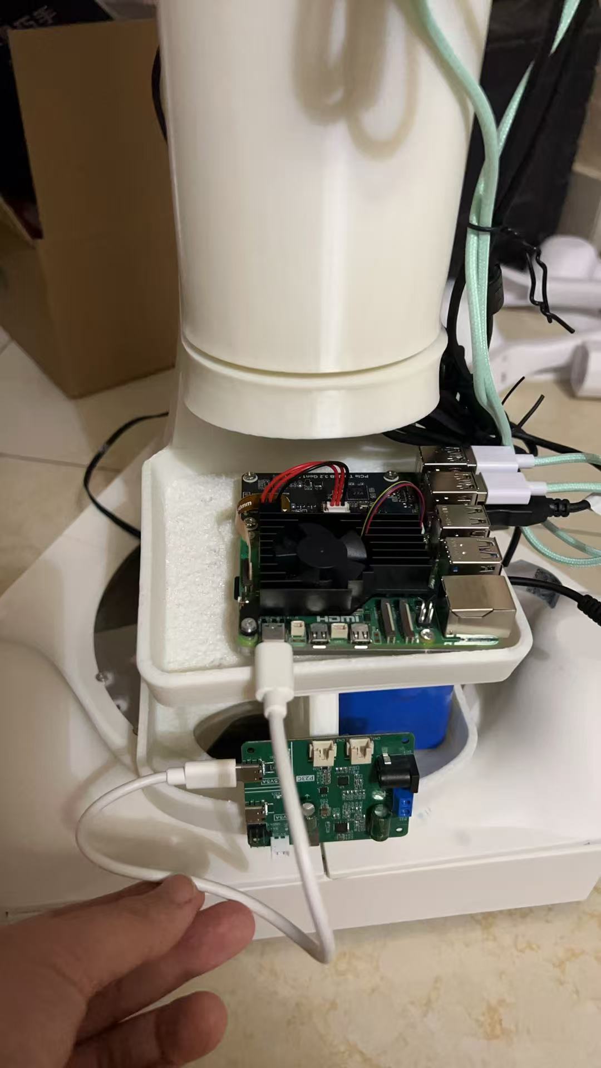
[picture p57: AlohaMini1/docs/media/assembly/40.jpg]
   

4. Connect the 12V lithium battery to the step-down converter to provide power.

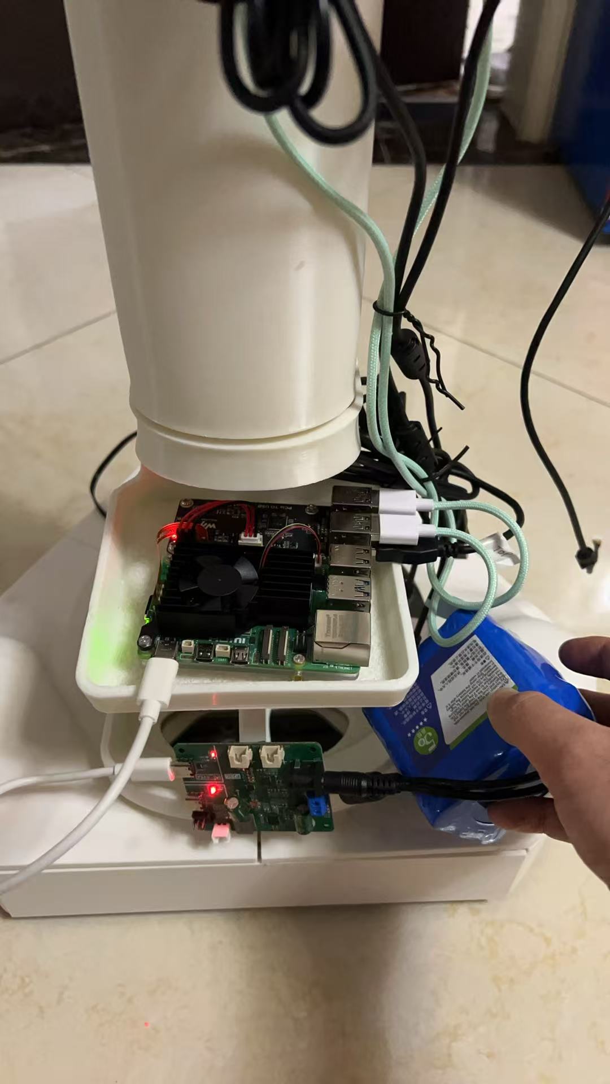
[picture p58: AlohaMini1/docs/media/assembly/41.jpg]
   

6. Connect the male plug of the 1-to-2 DC splitter cable to the female connectors of the two DC extension cables.
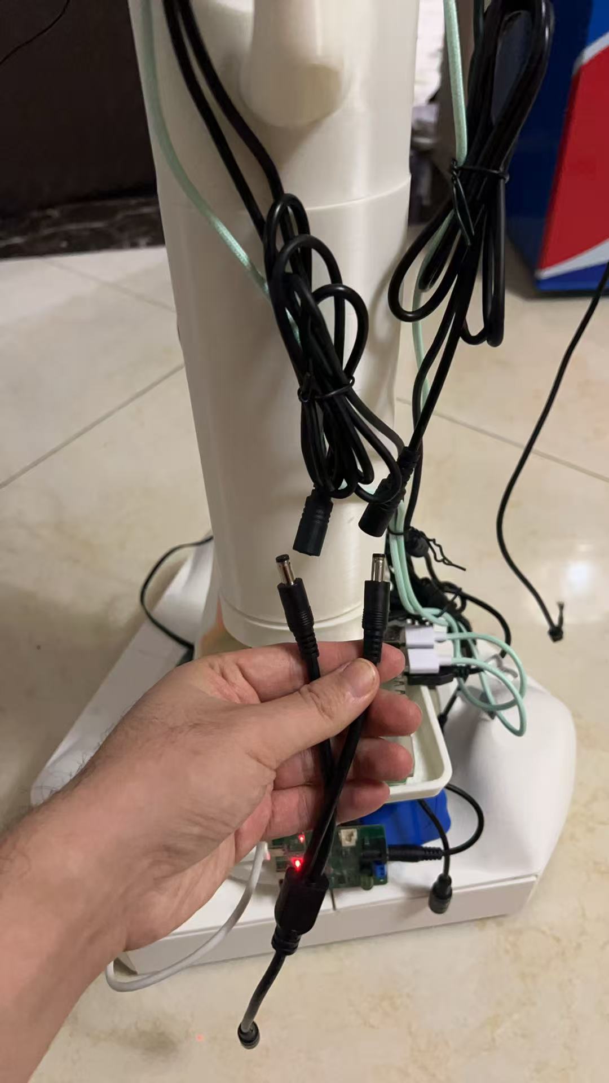
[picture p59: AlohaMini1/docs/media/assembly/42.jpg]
   

7. Connect the second 12V lithium battery to the female connector of the 1-to-2 DC splitter cable.
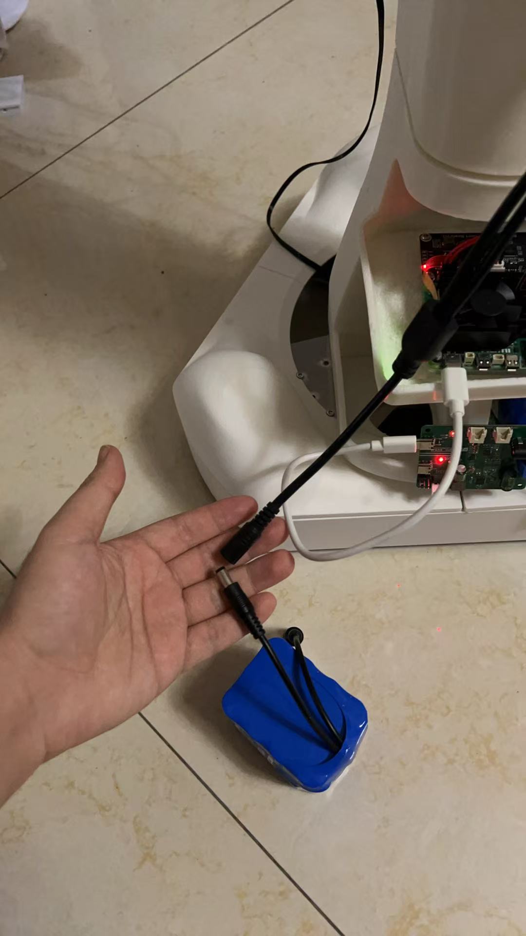
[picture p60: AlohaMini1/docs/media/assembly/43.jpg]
   

8. Assembly fully complete!
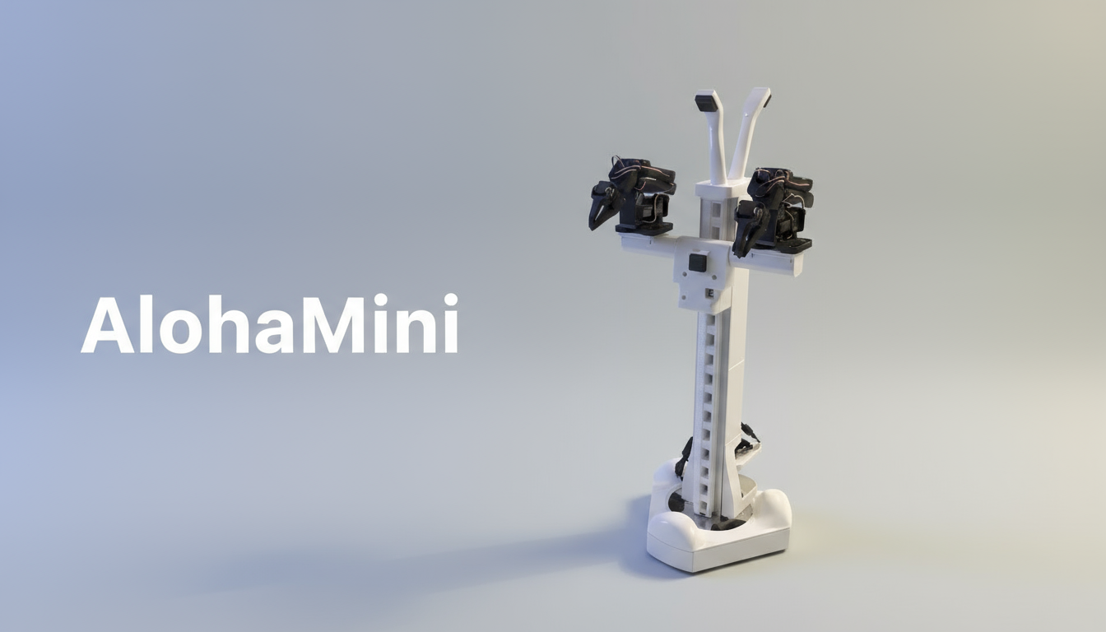
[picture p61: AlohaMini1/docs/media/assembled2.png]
   

## Optional Mobile Base Components

These optional parts add the touchscreen monitor enclosure, SO-101 arm adaptor plates for the `OB_T_Connector` parts, and camera covers with spacers.

### Touchscreen monitor enclosure

Use `Monitor_Enclosure` and `Monitor_Back_Panel` to enclose the 7-inch touchscreen monitor. The enclosure can be mounted to the main post after the monitor wiring has been routed. Fasten the enclosure with four M3×16 screws.

<table>
  <tr>
    <td align="center"></td>
    <td align="center"></td>
    <td align="center"></td>
  </tr>
  <tr>
    <td align="center">Front of monitor enclosure</td>
    <td align="center">Back panel and ventilation</td>
    <td align="center">Installed on the mobile base</td>
  </tr>
</table>

### SO-101 arm adaptor for the OB_T connectors

Use `OB_T_Connector_So101_Adaptor` between the SO-101 follower arms and the `OB_T_Connector` parts when adapting the arms to this mobile base. Check alignment before final tightening.

<table>
  <tr>
    <td align="center"></td>
    <td align="center"></td>
    <td align="center"></td>
  </tr>
  <tr>
    <td align="center">Adaptor side with connector slots</td>
    <td align="center">Adaptor mounting side</td>
    <td align="center">Adaptor installed with arms</td>
  </tr>
</table>

### Camera covers and spacers

Use `Camera_Cover` and `Camera_Spacers` for the camera modules. Insert the spacers between the camera board and cover, then fasten with 12 mm M2.5 screws. The BOM lists six M2.5×12 screws for this optional camera cover setup.

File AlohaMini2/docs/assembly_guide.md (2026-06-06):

# AlohaMini2 Assembly Guide

AlohaMini2 is the reinforced successor to AlohaMini1. It uses AM-ARM200 arms instead of SO-ARM100/101, upgrades the lift servo from STS-3215 to high-torque STS-3095, and strengthens the chassis for higher base loads. All printed parts are designed to fit a standard Bambu P2S printer.

This guide covers the AlohaMini2 Mobile Base 2 assembly. Prepare the follower and leader arms in advance using the [AM-ARM200 Assembly Guide](https://github.com/liyiteng/AM-ARM/tree/main/am-arm200).

## Servo ID Setup

Assign servo IDs before installing the servos. Configure one servo at a time to avoid ID conflicts.

| Servo | ID | Location |
|---|----|---|
| Rear-left wheel | 10 | Chassis |
| Front wheel | 9 | Chassis |
| Rear-right wheel | 8 | Chassis |
| Lift axis | 11 | Shoulder block |

### Using lerobot_alohamini

The recommended command is provided by the [`lerobot_alohamini`](https://github.com/liyiteng/lerobot_alohamini) repository. Clone that repository, install its dependencies, and run the command from the repository root:

```bash
git clone https://github.com/liyiteng/lerobot_alohamini.git
cd lerobot_alohamini
```

Example:

```bash
python examples/debug/motors.py configure_motor_id \
  --id 1 \
  --set_id 8 \
  --port /dev/ttyACM0
```

You can also use the Feetech FD Debug Tool through the Waveshare bus servo controller. Use baud rate `1000000`, scan the connected servo, write the target ID, then disconnect it before configuring the next servo.

## 1. Build the Chassis

Remove all print supports from the chassis parts, especially the wheel pockets, cable channels, and dowel-pin slots.

Chassis printed parts and fasteners

Apply epoxy to the mating surfaces.

Epoxy applied to chassis mating surfaces

Insert `OB_Chassis_Locking_Wedge.stl` into the locking-pin slot. The three chassis locking pins are tapered; install them in the correct direction so they can wedge the tower base tightly after assembly.

Chassis locking wedge installed

Apply epoxy to the `OB_Chassis_Frame_Joiner.stl` joiner, then press the chassis parts together until they are fully seated.

Chassis frame joiner before installation
Joined chassis frame

Install the three wheel servos in the chassis.

Wheel servos before installation

After assigning servo IDs, place the servos in the chassis in the orientation shown below.

Wheel servo ID layout in chassis

Connect servo 8 to servo 9, servo 9 to servo 10, and servo 10 to servo 11. Because servos 10 and 11 are far apart, use at least a 90 cm 3-pin servo cable; a 140 cm cable is recommended. Fasten the servos with the screws supplied with the servos.

Wheel servo cable routing

## 2. Install the Omni Wheels

Pre-install four M3x10 screws into each wheel-to-servo connector. Press the connector onto the servo output disc, confirm that all four mounting holes are aligned, then tighten the screws through the access opening.

Wheel connectors and M3x10 screws
Wheel connector on servo output disc
Tightening the wheel connector through the access opening

Install each omni wheel with its axle, 12x18x4 mm bearings, washers, and bearing cover.

Omni wheel axle and bearing hardware
Installing the omni wheel axle
Installed omni wheel bearing cover

The chassis assembly is now complete. At this point, you can use the debug command in the `lerobot_alohamini` repository to drive the base directly for a first test.

```bash
python examples/debug/wheels.py --port /dev/ttyACM0  # W/S/A/D drive test
```

Completed chassis during drive test

## 3. Build and Mount the Lift Tower

Build the tower in this order:

`O_POST4_Connector_Base.stl -> O_Main_Assembly_Post4.stl -> OB_Main_Assembly_Post3.stl -> OB_Main_Assembly_Post2.stl -> OB_Main_Assembly_Post1.stl`

Apply epoxy to each contact surface, stack the parts in order, and wipe away excess adhesive before it cures.

Lift tower printed parts
Assembled lift tower

Place the chassis with servo 9 facing you. The lift rack should also face you. Press the tower's hex base into the chassis socket, flip the assembly over, and tap evenly around the six side faces until the flange sits fully flush with the chassis.

Lift tower orientation in chassis socket
Locking the tower base into the chassis

Route the wheel servo cable through the center hole and side cable channels, then return the base upright.

Wheel servo cable routed through center hole
Wheel servo cable routed through side channels

## 4. Build the Shoulder Lift Block

Press the eight 4x13x5 mm track bearings into the shoulder bearing block. All bearings should sit flush and rotate freely.

Shoulder bearing block and track bearings
Installing track bearings into the shoulder block

Pre-install four M3x10 screws into the lift gear, then insert the 12x25 mm shaft from the right side. Rotate the gear until the screw tips drop into the servo output disc holes, then tighten the screws through the side access windows.

Lift gear hardware
Lift gear aligned with servo output disc
Lift axis shaft installed through the shoulder block

Bond the shoulder T-frame with epoxy and let it fully cure before loading the arms.

Bonded shoulder T-frame

Slide the shoulder T-frame onto the tower rails. It should travel smoothly without binding.

Shoulder lift block installed on tower rails

## 5. Install the Cameras

Install the two top cameras into the printed top camera mounts. Remove each camera back cover, place the printed mount/back-cover part between the camera body and cover, and fasten it with two M2x12 screws.

Top camera mount parts
Top camera back cover installation
Top camera installed in printed mount

Install the chest camera in the front bracket using the same back-cover mounting method.

Chest camera mount parts
Chest camera back cover installation
Chest camera installed in front bracket

## 6. Mount the Follower Arms and Route Cables

Fasten the left and right follower arms to the shoulder T-frame using the long M3 socket screws and M3 nuts. One arm mounts on each side.

Follower arms mounted to the shoulder T-frame
Follower arm mounting fasteners

Feed the arm and camera cables through the cable ports in the lift tower.

Cable port in the lift tower
Arm and camera cables routed through the tower

Connect the 3-pin cable from lift servo 11 to the servo driver board on the left arm. Leave enough slack for the shoulder to move through its full vertical travel.

| Side | Cable bundle |
|---|---|
| Left | Arm power, arm Type-C, wrist camera USB, chest camera USB, lift servo cable |
| Right | Arm power, arm Type-C, wrist camera USB |

Slide protective cable sleeves over the routed bundles.

Left cable bundle
Right cable bundle
Protective cable sleeves installed

## 7. Install Display, Compute, and Power

Fasten the display to its printed bracket with four M3x6 screws, slide the bracket into the rear dovetail slot, and connect the short micro-HDMI cable plus Type-C power cable.

Display bracket parts
Display mounted on rear dovetail bracket

Mount the Raspberry Pi 5, buck converter, battery packs, and counterweight in the rear support.

Raspberry Pi, buck converter, batteries, and counterweight in rear support

Wire power as follows:

| Power path | Connection |
|---|---|
| Arm power | Battery 1 -> 2-to-1 splitter -> left and right arm DC cables |
| Compute power | Battery 2 -> buck converter -> Raspberry Pi Type-C power port |

AlohaMini2 power wiring

## 8. Functional Test

Before running the full robot, test each moving subsystem:

```bash
python examples/debug/wheels.py --port /dev/ttyACM0  # W/S/A/D drive test
python examples/debug/axis.py --port /dev/ttyACM0    # U/J lift test
```

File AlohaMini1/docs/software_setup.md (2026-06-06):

# software_setup

There are two ways to run **AlohaMini** with **LeRobot**:

## **Method 1 — For existing LeRobot users**
If you’re already familiar with LeRobot, simply copy the files from  
`alohamini/software` into your existing LeRobot workspace.  
Then follow the configuration and command-line examples in the repository:  
👉 **https://github.com/liyiteng/lerobot_alohamini**

## **Method 2 — Recommended for beginners**
If you’re new to LeRobot and haven’t set it up before, it’s easier to clone the integrated repository directly:  
👉 **https://github.com/liyiteng/lerobot_alohamini**

This repository bundles **LeRobot + AlohaMini** together, so no manual copying or path configuration is required.

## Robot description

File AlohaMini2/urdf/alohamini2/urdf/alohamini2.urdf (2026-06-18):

<?xml version="1.0" encoding="utf-8"?>
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
<robot name="alohamini2_urdf">

 <link name="root">
    <inertial>
      <mass value="0"/>
      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
    </inertial>
  </link>

  <link name="root_x_link">
    <inertial>
      <mass value="0"/>
      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
    </inertial>
  </link>

  <link name="root_y_link">
    <inertial>
      <mass value="0"/>
      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
    </inertial>
  </link>

  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
  <joint name="root_x_axis_joint" type="prismatic">
    <parent link="root"/>
    <child link="root_x_link"/>
    <axis xyz="1 0 0"/>
    <limit effort="500" lower="-20" upper="20" velocity="1.0"/>
    <dynamics damping="100.0" friction="10"/>
  </joint>

  <joint name="root_y_axis_joint" type="prismatic">
    <parent link="root_x_link"/>
    <child link="root_y_link"/>
    <axis xyz="0 1 0"/>
    <limit effort="500" lower="-20" upper="20" velocity="1.0"/>
    <dynamics damping="100.0" friction="10"/>
  </joint>

  <joint name="root_z_rotation_joint" type="continuous">
    <parent link="root_y_link"/>
    <child link="base_link"/>
    <axis xyz="0 0 1"/>
    <dynamics damping="100.0" friction="10"/>
  </joint>




  <link name="base_link">
    <inertial>
      <origin xyz="-0.000612633316587952 0.0211982181323527 0.18480862701929" rpy="0 0 0" />
      <mass value="8.86139507603108" />
      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
    </inertial>
    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
  </link>
  <link name="vertical_link">
    <inertial>
      <origin xyz="-0.000482088964298404 -0.0410546516336574 0.425062657231215" rpy="0 0 0" />
      <mass value="1.2335419276614" />
      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
    </inertial>
    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
  </link>
  <joint name="vertical_move" type="prismatic">
    <origin xyz="0 0 0.096196" rpy="0 0 0" />
    <parent link="base_link" />
    <child link="vertical_link" />
    <axis xyz="0 0 1" />
    <limit lower="-0.3" upper="0.3" effort="0" velocity="0" />
  </joint>
  <link name="chest_camera">
    <inertial>
      <origin xyz="0.318266847861093 -0.000370150448734445 -0.0826066487973801" rpy="0 0 0" />
      <mass value="10.0950259540064" />
      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
    </inertial>
    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
  </link>
  <joint name="chest_camera_joint7_dp" type="fixed">
    <origin xyz="-0.000225761875701821 -0.0690163597583236 0.447985436693376" rpy="1.57079632679491 1.5707963267949 0" />
    <parent link="vertical_link" />
    <child link="chest_camera" />
    <axis xyz="0 0 0" />
  </joint>
  <link name="Link2_dp">
    <inertial>
      <origin xyz="-0.162572857658571 -0.0120532949042898 -0.146727084322472" rpy="0 0 0" />
      <mass value="10.0950259540064" />
      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
    </inertial>
    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
  </link>
  <joint name="joint2_dp" type="fixed">
    <origin xyz="-0.1337 0.076522 0.063355" rpy="3.3411E-05 1.5707 2.618" />
    <parent link="base_link" />
    <child link="Link2_dp" />
    <axis xyz="-8.7287E-05 0 -1" />
  </joint>
  <link name="Link3_dp">
    <inertial>
      <origin xyz="-0.162560049646843 0.000838249024472069 -0.166596420117959" rpy="0 0 0" />
      <mass value="10.0950259540064" />
      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
    </inertial>
    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
  </link>
  <joint name="joint3_dp" type="fixed">
    <origin xyz="-0.0014342 -0.15301 0.063355" rpy="1.5708 1.5708 0" />
    <parent link="base_link" />
    <child link="Link3_dp" />
    <axis xyz="0 0 -1" />
  </joint>
  <link name="Link4_dp">
    <inertial>
      <origin xyz="-0.01147039688487 -0.162560049646841 -0.145503153867049" rpy="0 0 0" />
      <mass value="10.0950259540064" />
      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
    </inertial>
    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
  </link>
  <joint name="joint4_dp" type="fixed">
    <origin xyz="0.13115 0.076408 0.063355" rpy="-1.5708 0 -1.0472" />
    <parent link="base_link" />
    <child link="Link4_dp" />
    <axis xyz="0 0 -1" />
  </joint>
  <link name="back_camera">
    <inertial>
      <origin xyz="-0.640890595074529 -0.00093675959900047 0.610115206341962" rpy="0 0 0" />
      <mass value="10.0950259540064" />
      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
    </inertial>
    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
  </link>
  <joint name="back_camera_joint5_dp" type="fixed">
    <origin xyz="0.00034085 0.16827 1.0972" rpy="-3.1416 -0.63429 1.5708" />
    <parent link="base_link" />
    <child link="back_camera" />
    <axis xyz="0 0 0" />
  </joint>
  <link name="front_camera">
    <inertial>
      <origin xyz="0.667531496762255 -0.00090519797224118 0.570675109672329" rpy="0 0 0" />
      <mass value="10.0950259540064" />
      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
    </inertial>
    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
  </link>
  <joint name="front_camera_joint6_dp" type="fixed">
    <origin xyz="0.000309285647814801 -0.0549084504780031 1.10145847792887" rpy="-3.14159265358978 0.78538567812397 1.5707963267949" />
    <parent link="base_link" />
    <child link="front_camera" />
    <axis xyz="0 0 0" />
  </joint>

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
<link name="left_Base">
    <inertial>
      <origin xyz="-2.45960666746703E-07 0.0311418169687909 0.0175746661003382" rpy="0 0 0" />
      <mass value="0.193184127927598" />
      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
    </inertial>
    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
  </link>

  <joint name="left_base_joint" type="fixed">
    <origin xyz="0.18726 -0.0599 0.4775" rpy="0 0 0" />
    <parent link="vertical_link" />
    <child link="left_Base" />
  </joint>
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

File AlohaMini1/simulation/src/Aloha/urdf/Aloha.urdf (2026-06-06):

<?xml version="1.0" encoding="utf-8"?>
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
<robot name="Aloha">
  <link name="base_link">
    <inertial>
      <origin xyz="-0.00084647910851246 0.00978916757496985 0.344753325406094" rpy="0 0 0" />
      <mass value="5.09802085015176" />
      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
    </inertial>
    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
  </link>
  <link name="wheel1">
    <inertial>
      <origin xyz="-5.2748796340582E-05 0.0157741139634841 -1.84430449176598E-07" rpy="0 0 0" />
      <mass value="0.19481896281763" />
      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
    </inertial>
    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
  </link>
  <joint name="wheel1" type="continuous">
    <origin xyz="-0.1538 0.091161 0.0422" rpy="0 0 -2.1099" />
    <parent link="base_link" />
    <child link="wheel1" />
    <axis xyz="0 -1 0" />
  </joint>
  <link name="wheel2">
    <inertial>
      <origin xyz="-6.44947300230958E-06 0.0157740656100239 -5.23561600380557E-05" rpy="0 0 0" />
      <mass value="0.194818035649416" />
      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
    </inertial>
    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
  </link>
  <joint name="wheel2" type="continuous">
    <origin xyz="0.15563 0.087993 0.0422" rpy="0 0 2.086" />
    <parent link="base_link" />
    <child link="wheel2" />
    <axis xyz="0 -1 0" />
  </joint>
  <link name="wheel3">
    <inertial>
      <origin xyz="0.000217589099159171 0.0157726511952609 -4.56400979924609E-05" rpy="0 0 0" />
      <mass value="0.194818526867466" />
      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
    </inertial>
    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
  </link>
  <joint name="wheel3" type="continuous">
    <origin xyz="-0.0020354 -0.17875 0.0422" rpy="0 0 0" />
    <parent link="base_link" />
    <child link="wheel3" />
    <axis xyz="-0.015476 -0.99988 0" />
  </joint>
  <link name="vertical_link">
    <inertial>
      <origin xyz="-0.000281866140488002 0.00785823838067955 0.630167237552405" rpy="0 0 0" />
      <mass value="1.13349901272872" />
      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
    </inertial>
    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
  </link>
  <joint name="vertical_move" type="prismatic">
    <origin xyz="-0.001045 -0.067891 0.064" rpy="0 0 0" />
    <parent link="base_link" />
    <child link="vertical_link" />
    <axis xyz="0 1.8801E-05 1" />
    <limit lower="0" upper="0" effort="0" velocity="0" />
  </joint>
  <link name="left_base">
    <inertial>
      <origin xyz="-6.47167646904735E-05 0.0317790321031433 0.0165976346519832" rpy="0 0 0" />
      <mass value="0.198100409133884" />
      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
    </inertial>
    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
  </link>
  <joint name="left_base" type="fixed">
    <origin xyz="0.15726 0.026474 0.68821" rpy="1.5721 0 -0.01193" />
    <parent link="vertical_link" />
    <child link="left_base" />
    <axis xyz="0 0 0" />
  </joint>
  <link name="left_link1">
    <inertial>
      <origin xyz="0.000121106970690763 -0.0313187111675913 0.0119674003207884" rpy="0 0 0" />
      <mass value="0.124705001245189" />
      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
    </inertial>
    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
  </link>
  <joint name="left_joint1" type="revolute">
    <origin xyz="-9.9427E-05 0.065387 0.045495" rpy="-1.5721 0.01193 -1.5058E-05" />
    <parent link="left_base" />
    <child link="left_link1" />
    <axis xyz="0.00011908 0.0099879 -0.99995" />
    <limit lower="0" upper="0" effort="0" velocity="0" />
  </joint>
  <link name="left_link2">
    <inertial>
      <origin xyz="0.019956873522225 0.0742856296056551 0.00422113879640418" rpy="0 0 0" />
      <mass value="0.159995189384934" />
      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
    </inertial>
    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
  </link>
  <joint name="left_joint2" type="revolute">
    <origin xyz="-0.0172799395963306 -0.0311811002780606 0.0539361523404946" rpy="0 0 0" />
    <parent link="left_link1" />
    <child link="left_link2" />
    <axis xyz="0.999994864047587 -0.00320379392081127 8.70801950002401E-05" />
    <limit lower="0" upper="0" effort="0" velocity="0" />
  </joint>
  <link name="left_link3">
    <inertial>
      <origin xyz="0.0188635530589078 -0.0764818324673495 0.000740365189654368" rpy="0 0 0" />
      <mass value="0.135542971850972" />
      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
    </inertial>
    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
  </link>
  <joint name="left_joint3" type="revolute">
    <origin xyz="0.0028523 0.11238 0.028829" rpy="0 0 0" />
    <parent link="left_link2" />
    <child link="left_link3" />
    <axis xyz="0.99996 -0.0032908 0.0088132" />
    <limit lower="0" upper="0" effort="0" velocity="0" />
  </joint>
  <link name="left_link4">
    <inertial>
      <origin xyz="0.0279838202754113 -0.0363068236889853 0.000384829033235112" rpy="0 0 0" />
      <mass value="0.0742878691881685" />
      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
    </inertial>
    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
  </link>
  <joint name="left_joint4" type="revolute">
    <origin xyz="0.00048209729405399 -0.134148581563103 0.00362381075655138" rpy="0 0 0" />
    <parent link="left_link3" />
    <child link="left_link4" />
    <axis xyz="0.999774464019127 -0.0121028846500289 0.0174511110940406" />
    <limit lower="0" upper="0" effort="0" velocity="0" />
  </joint>
  <link name="left_link5">
    <inertial>
      <origin xyz="8.08393796061513E-05 -0.0263409418103688 -0.00560236977442241" rpy="0 0 0" />
      <mass value="0.0992047568868334" />
      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
    </inertial>
    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
  </link>
  <joint name="left_joint5" type="revolute">
    <origin xyz="0.0197383915384675 -0.0617903364033804 -0.000262136225517406" rpy="0 0 0" />
    <parent link="left_link4" />
    <child link="left_link5" />
    <axis xyz="0.0119284594940202 0.999878198776736 0.0100647635386641" />
    <limit lower="0" upper="0" effort="0" velocity="0" />
  </joint>
  <link name="left_link6">
    <inertial>
      <origin xyz="-0.0204038927902523 -0.00159758044103914 0.029746450173969" rpy="0 0 0" />
      <mass value="0.0208454114831758" />
      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
    </inertial>
    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
  </link>
  <joint name="left_joint6" type="revolute">
    <origin xyz="0.0187720220742788 -0.0238281541937461 0.0200035092438084" rpy="0 0 0" />
    <parent link="left_link5" />
    <child link="left_link6" />
    <axis xyz="-0.999889727846743 0.0120164296808642 -0.00872568417324989" />
    <limit lower="0" upper="0" effort="0" velocity="0" />
  </joint>
  <link name="right_base">
    <inertial>
      <origin xyz="-6.47167852975139E-05 0.0317790320234692 0.0165976345779274" rpy="0 0 0" />
      <mass value="0.198100409607737" />
      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
    </inertial>
    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
  </link>
  <joint name="right_base" type="fixed">
    <origin xyz="-0.156575640990368 0.0302182544430658 0.688907726663402" rpy="1.5720584644847 0 -0.0119300103453133" />
    <parent link="vertical_link" />
    <child link="right_base" />
    <axis xyz="0 0 0" />
  </joint>
  <link name="right_link1">
    <inertial>
      <origin xyz="0.000121106969499962 -0.0313187111595207 0.011967400309894" rpy="0 0 0" />
      <mass value="0.124705001332934" />
      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
    </inertial>
    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
  </link>
  <joint name="right_joint1" type="revolute">
    <origin xyz="-9.94268621290484E-05 0.0653870978342812 0.04549462735273" rpy="-1.5720585543069 0.0119300008426609 -1.50580260816763E-05" />
    <parent link="right_base" />
    <child link="right_link1" />
    <axis xyz="0.000119075661457425 0.00998790806073686 -0.999950112512398" />
    <limit lower="0" upper="0" effort="0" velocity="0" />
  </joint>
  <link name="right_link2">
    <inertial>
      <origin xyz="0.0199568735153524 0.0742856296207353 0.00422113879547792" rpy="0 0 0" />
      <mass value="0.159995189339826" />
      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

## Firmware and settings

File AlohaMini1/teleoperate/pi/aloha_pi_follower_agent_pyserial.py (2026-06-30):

#!/usr/bin/env python3
"""Raspberry Pi HTTP receiver for AlohaMini1 base and lift servos using pyserial."""

from __future__ import annotations

import argparse
import json
import math
import sys
import threading
import time
from http.server import BaseHTTPRequestHandler, ThreadingHTTPServer

import serial

DEFAULT_FRONT_ID = 9
DEFAULT_BACK_LEFT_ID = 8
DEFAULT_BACK_RIGHT_ID = 10
DEFAULT_LIFT_ID = 11


def checksum(data: list[int]) -> int:
    return (~(sum(data) & 0xFF)) & 0xFF


def send_packet(bus: serial.Serial, servo_id: int, instruction: int, params: list[int] | None = None) -> None:
    params = params or []
    body = [servo_id, len(params) + 2, instruction, *params]
    packet = bytes([0xFF, 0xFF, *body, checksum(body)])
    bus.reset_input_buffer()
    bus.write(packet)
    bus.flush()
    time.sleep(0.003)


def drain_response(bus: serial.Serial, timeout: float = 0.025) -> None:
    deadline = time.monotonic() + timeout
    while time.monotonic() < deadline:
        if bus.in_waiting:
            bus.read(bus.in_waiting)
        time.sleep(0.001)


def write_byte(bus: serial.Serial, servo_id: int, address: int, value: int) -> None:
    send_packet(bus, servo_id, 0x03, [address & 0xFF, value & 0xFF])
    drain_response(bus)


def write_word(bus: serial.Serial, servo_id: int, address: int, value: int) -> None:
    value &= 0xFFFF
    send_packet(bus, servo_id, 0x03, [address & 0xFF, value & 0xFF, (value >> 8) & 0xFF])
    drain_response(bus)


def encode_speed(speed: int) -> int:
    if abs(speed) > 32767:
        raise ValueError("Speed magnitude must be <= 32767")
    return 32768 + abs(speed) if speed < 0 else speed


def set_velocity_mode(bus: serial.Serial, servo_id: int) -> None:
    # STS3215 velocity-mode register sequence from the working AlohaMini1 controller.
    write_byte(bus, servo_id, 40, 0)
    write_byte(bus, servo_id, 55, 0)
    write_byte(bus, servo_id, 33, 1)
    write_byte(bus, servo_id, 55, 1)
    write_byte(bus, servo_id, 40, 1)


def set_speed(bus: serial.Serial, servo_id: int, speed: int) -> None:
    write_word(bus, servo_id, 46, encode_speed(speed))


def normalize_speeds(speeds: dict[int, int], max_magnitude: int = 32767) -> dict[int, int]:
    largest = max(abs(value) for value in speeds.values())
    if largest <= max_magnitude or largest == 0:
        return speeds
    scale = max_magnitude / largest
    return {servo_id: round(value * scale) for servo_id, value in speeds.items()}


def mix_base_speeds(args, forward_speed: int, turn_speed: int) -> dict[int, int]:
    raw_front = turn_speed
    raw_back_left = (-0.866 * forward_speed) + turn_speed
    raw_back_right = (0.866 * forward_speed) + turn_speed
    return normalize_speeds(
        {
            args.front_id: round(raw_front * args.front_sign),
            args.back_left_id: round(raw_back_left * args.back_left_sign),
            args.back_right_id: round(raw_back_right * args.back_right_sign),
        }
    )


class RobotState:
    def __init__(self, bus: serial.Serial, args):
        self.bus = bus
        self.args = args
        self.timeout = args.timeout
        self.lock = threading.Lock()
        self.last_command = 0.0
        self.last_base_speeds: dict[int, int] | None = None
        self.last_lift_speed: int | None = None
        self.command_count = 0
        self.last_error = ""
        self.running = True

    @property
    def base_ids(self) -> tuple[int, int, int]:
        return (self.args.front_id, self.args.back_left_id, self.args.back_right_id)

    def apply(self, base_forward: int, base_turn: int, lift: int) -> None:
        base_speeds = mix_base_speeds(self.args, base_forward, base_turn)
        with self.lock:
            if base_speeds != self.last_base_speeds:
                for servo_id in self.base_ids:
                    set_speed(self.bus, servo_id, base_speeds[servo_id])
                self.last_base_speeds = base_speeds
            if lift != self.last_lift_speed:
                set_speed(self.bus, self.args.lift_id, lift)
                self.last_lift_speed = lift
            self.last_command = time.monotonic()
            self.command_count += 1
            self.last_error = ""

    def stop(self) -> None:
        with self.lock:
            for servo_id in self.base_ids:
                set_speed(self.bus, servo_id, 0)
            set_speed(self.bus, self.args.lift_id, 0)
            self.last_base_speeds = {servo_id: 0 for servo_id in self.base_ids}
            self.last_lift_speed = 0

    def snapshot(self) -> dict[str, object]:
        with self.lock:
            age = time.monotonic() - self.last_command if self.last_command else math.inf
            return {
                "ok": not self.last_error,
                "command_count": self.command_count,
                "last_command_age": None if math.isinf(age) else round(age, 3),
                "timeout": self.timeout,
                "base_speeds": self.last_base_speeds,
                "lift_speed": self.last_lift_speed,
                "last_error": self.last_error,
                "servo_ids": {"front": self.args.front_id, "back_left": self.args.back_left_id, "back_right": self.args.back_right_id, "lift": self.args.lift_id},
            }

    def watchdog_loop(self) -> None:
        while self.running:
            age = time.monotonic() - self.last_command if self.last_command else math.inf
            if age > self.timeout:
                try:
                    self.stop()
                except Exception as exc:
                    with self.lock:
                        self.last_error = str(exc)
            time.sleep(0.05)


def make_handler(robot: RobotState):
    class Handler(BaseHTTPRequestHandler):
        def log_message(self, fmt, *args):
            return

        def write_json(self, status: int, payload: dict[str, object]) -> None:
            body = json.dumps(payload).encode("utf-8")
            self.send_response(status)
            self.send_header("Content-Type", "application/json")
            self.send_header("Content-Length", str(len(body)))
            self.end_headers()
            self.wfile.write(body)

        def do_GET(self):
            if self.path == "/status":
                self.write_json(200, robot.snapshot())
                return
            self.send_error(404)

        def do_POST(self):
            if self.path == "/stop":
                try:
                    robot.stop()
                    self.write_json(200, {"ok": True, "stopped": True})
                except Exception as exc:
                    self.write_json(500, {"ok": False, "error": str(exc)})
                return
            if self.path != "/command":
                self.send_error(404)
                return
            length = int(self.headers.get("Content-Length", "0"))
            try:
                payload = json.loads(self.rfile.read(length).decode("utf-8"))
                robot.apply(int(payload.get("base_forward", 0)), int(payload.get("base_turn", 0)), int(payload.get("lift", 0)))
                self.write_json(200, {"ok": True})
            except Exception as exc:
                with robot.lock:
                    robot.last_error = str(exc)
                try:
                    robot.stop()
                finally:
                    self.write_json(400, {"ok": False, "error": str(exc)})

    return Handler


def build_parser() -> argparse.ArgumentParser:
    parser = argparse.ArgumentParser(description="Aloha Mini Raspberry Pi base/lift follower agent using pyserial")
    parser.add_argument("--servo-port", default="/dev/ttyACM0", help="Servo bus path; prefer /dev/serial/by-id/... on the Pi")
    parser.add_argument("--baud", type=int, default=1_000_000)
    parser.add_argument("--host", default="0.0.0.0")
    parser.add_argument("--port", type=int, default=9000)
    parser.add_argument("--front-id", type=int, default=DEFAULT_FRONT_ID)
    parser.add_argument("--back-left-id", type=int, default=DEFAULT_BACK_LEFT_ID)
    parser.add_argument("--back-right-id", type=int, default=DEFAULT_BACK_RIGHT_ID)
    parser.add_argument("--lift-id", type=int, default=DEFAULT_LIFT_ID)
    parser.add_argument("--front-sign", type=int, choices=[-1, 1], default=1)
    parser.add_argument("--back-left-sign", type=int, choices=[-1, 1], default=-1)
    parser.add_argument("--back-right-sign", type=int, choices=[-1, 1], default=-1)
    parser.add_argument("--timeout", type=float, default=0.35)
    parser.add_argument("--setup-velocity-mode", action="store_true")
    return parser


def main() -> int:
    args = build_parser().parse_args()
    bus = serial.Serial(args.servo_port, args.baud, timeout=0.1, write_timeout=0.1)
    time.sleep(0.15)
    try:
        if args.setup_velocity_mode:
            for servo_id in (args.front_id, args.back_left_id, args.back_right_id, args.lift_id):
                print(f"Setting ID {servo_id} to velocity mode...", flush=True)
                set_velocity_mode(bus, servo_id)
        robot = RobotState(bus, args)
        robot.stop()
        threading.Thread(target=robot.watchdog_loop, daemon=True).start()
        server = ThreadingHTTPServer((args.host, args.port), make_handler(robot))
        print(f"Aloha Pi base/lift agent listening on http://{args.host}:{args.port}", flush=True)
        print(f"Servo bus: {args.servo_port} at {args.baud}", flush=True)
        print("POST /command with base_forward, base_turn, lift. Ctrl+C to stop.", flush=True)
        try:
            server.serve_forever()
        finally:
            robot.running = False
            robot.stop()
            server.server_close()
            print("Stopped all servos.", flush=True)
        return 0
    finally:
        bus.close()


if __name__ == "__main__":
    try:
        raise SystemExit(main())
    except KeyboardInterrupt:
        print("\nInterrupted.", file=sys.stderr)

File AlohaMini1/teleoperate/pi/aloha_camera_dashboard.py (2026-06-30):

#!/usr/bin/env python3
"""Optional Raspberry Pi camera dashboard and recorder for AlohaMini1.

Edit CAMERAS for your own /dev/v4l/by-path camera names. Find them with:
  ls -l /dev/v4l/by-path/
"""

from __future__ import annotations

import argparse
import json
import signal
import subprocess
import threading
from datetime import datetime
from http.server import BaseHTTPRequestHandler, ThreadingHTTPServer
from pathlib import Path
from urllib.parse import urlparse

CAMERAS = {
    "right_wrist": "/dev/v4l/by-path/REPLACE_WITH_RIGHT_WRIST_CAMERA",
    "front_post": "/dev/v4l/by-path/REPLACE_WITH_FRONT_POST_CAMERA",
    "chest_lift": "/dev/v4l/by-path/REPLACE_WITH_CHEST_LIFT_CAMERA",
    "left_wrist": "/dev/v4l/by-path/REPLACE_WITH_LEFT_WRIST_CAMERA",
    "back_post": "/dev/v4l/by-path/REPLACE_WITH_BACK_POST_CAMERA",
}

record_lock = threading.Lock()
recording_dir = None
recording_procs = {}

HTML = """<!doctype html>
<html>
<head>
<meta charset="utf-8">
<title>Aloha Mini Cameras</title>
<style>
  body { margin: 0; background: #111; color: #eee; font-family: Arial, sans-serif; }
  header { height: 56px; display: flex; align-items: center; gap: 12px; padding: 0 16px; background: #1b1b1b; border-bottom: 1px solid #333; }
  button { padding: 8px 12px; border: 1px solid #555; background: #2b2b2b; color: #eee; cursor: pointer; }
  #status { color: #bbb; }
  .grid { display: grid; grid-template-columns: 1fr 1fr 1fr; gap: 8px; padding: 8px; }
  .cam { background: #050505; border: 1px solid #333; min-height: 220px; position: relative; }
  .cam h2 { position: absolute; left: 8px; top: 6px; margin: 0; font-size: 14px; background: rgba(0,0,0,.55); padding: 4px 7px; }
  .cam img { width: 100%; height: 100%; object-fit: contain; display: block; }
</style>
</head>
<body>
<header>
  <strong>Aloha Mini Cameras</strong>
  <button onclick="startRec()">Start Recording</button>
  <button onclick="stopRec()">Stop Recording</button>
  <span id="status">checking...</span>
</header>
<div class="grid">CAMERA_CARDS</div>
<script>
async function refreshStatus() {
  const r = await fetch('/status');
  const s = await r.json();
  document.getElementById('status').textContent = s.recording ? `recording: ${s.recording_dir}` : 'not recording';
}
async function startRec() { await fetch('/record/start', {method:'POST'}); refreshStatus(); }
async function stopRec() { await fetch('/record/stop', {method:'POST'}); refreshStatus(); }
setInterval(refreshStatus, 1000);
refreshStatus();
</script>
</body>
</html>
"""


def enabled_cameras():
    return {name: device for name, device in CAMERAS.items() if "REPLACE_WITH" not in device}


def camera_cards():
    cards = []
    for name in enabled_cameras():
        cards.append(f'<section class="cam"><h2>{name}</h2><img src="/stream/{name}"></section>')
    return "\n".join(cards) or "<p>No cameras configured. Edit CAMERAS in aloha_camera_dashboard.py.</p>"


def stream_cmd(device, width, height, fps):
    return ["ffmpeg", "-hide_banner", "-loglevel", "error", "-f", "v4l2", "-framerate", str(fps), "-video_size", f"{width}x{height}", "-i", device, "-q:v", "5", "-f", "mjpeg", "pipe:1"]


def record_cmd(device, width, height, fps, out_path):
    return ["ffmpeg", "-hide_banner", "-loglevel", "error", "-y", "-f", "v4l2", "-framerate", str(fps), "-video_size", f"{width}x{height}", "-i", device, "-c:v", "libx264", "-preset", "ultrafast", "-pix_fmt", "yuv420p", str(out_path)]


def stop_recording():
    global recording_dir, recording_procs
    with record_lock:
        for proc in recording_procs.values():
            if proc.poll() is None:
                proc.send_signal(signal.SIGINT)
        for proc in recording_procs.values():
            try:
                proc.wait(timeout=5)
            except subprocess.TimeoutExpired:
                proc.kill()
        recording_procs = {}
        recording_dir = None


def make_handler(args):
    class Handler(BaseHTTPRequestHandler):
        def log_message(self, fmt, *vals):
            return

        def send_json(self, obj, code=200):
            data = json.dumps(obj).encode()
            self.send_response(code)
            self.send_header("Content-Type", "application/json")
            self.send_header("Content-Length", str(len(data)))
            self.end_headers()
            self.wfile.write(data)

        def do_GET(self):
            path = urlparse(self.path).path
            cameras = enabled_cameras()
            if path in ("/", "/index.html"):
                page = HTML.replace("CAMERA_CARDS", camera_cards()).encode()
                self.send_response(200)
                self.send_header("Content-Type", "text/html; charset=utf-8")
                self.send_header("Content-Length", str(len(page)))
                self.end_headers()
                self.wfile.write(page)
                return
            if path == "/status":
                with record_lock:
                    self.send_json({"recording": bool(recording_procs), "recording_dir": str(recording_dir) if recording_dir else None, "cameras": cameras})
                return
            if path.startswith("/stream/"):
                name = path.split("/", 2)[2]
                if name not in cameras:
                    self.send_error(404)
                    return
                self.stream_camera(cameras[name])
                return
            self.send_error(404)

        def do_POST(self):
            global recording_dir, recording_procs
            path = urlparse(self.path).path
            cameras = enabled_cameras()
            if path == "/record/start":
                with record_lock:
                    if recording_procs:
                        self.send_json({"ok": True, "already_recording": True, "dir": str(recording_dir)})
                        return
                    stamp = datetime.now().strftime("%Y-%m-%d_%H-%M-%S")
                    recording_dir = Path(args.output_dir).expanduser() / stamp
                    recording_dir.mkdir(parents=True, exist_ok=True)
                    (recording_dir / "metadata.json").write_text(json.dumps({"started_at": stamp, "width": args.width, "height": args.height, "fps": args.fps, "cameras": cameras}, indent=2))
                    for name, device in cameras.items():
                        recording_procs[name] = subprocess.Popen(record_cmd(device, args.width, args.height, args.fps, recording_dir / f"{name}.mp4"))
                    self.send_json({"ok": True, "dir": str(recording_dir)})
                return
            if path == "/record/stop":
                stop_recording()
                self.send_json({"ok": True})
                return
            self.send_error(404)
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

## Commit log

2026-06-06 feat: add AlohaMini2 support and major repository refactor
    [Aloha.csv, Aloha.urdf, D_Base_SO101_Lekiwi.stl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]
2026-06-06 feat: add README for AM-ARM200 arm platform integration
2026-06-06 fix: add links to arm and mobile base systems in README
2026-06-18 feat: add URDF files for AlohaMini2
    [alohamini2.urdf, alohamini2pro.urdf, back_camera.STL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]
2026-06-29 Add AlohaMini1 PC base lift steering sender
2026-06-30 Add optional AlohaMini1 camera dashboard
2026-06-30 Add optional pedal and phone steering hardware links
2026-06-30 Document optional pedal and phone steering hardware in templates
2026-06-30 Add face steering webcam reference
2026-06-30 Replace AlohaMini1 chassis plate STEP files
    [O_Chassis_Lower_Plate.stp, O_Chassis_Lower_Plate_A.step, O_Chassis_Lower_Plate_B.step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]
2026-06-30 Replace AlohaMini1 chassis plate STL files
    [O_Chassis_Lower_Plate.stl, O_Chassis_Lower_Plate_A.stl, O_Chassis_Lower_Plate_B.stl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]
2026-06-30 Add face steering example images
2026-06-30 Add AlohaMini1 mobile base monitor and camera parts
    [Camera_Cover.step, Camera_Cover.stl, Camera_Spacers.step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]
2026-06-30 Update AlohaMini1 BOM teleoperation hardware
2026-06-30 Document monitor enclosure screws
2026-06-30 Correct BOM screw head types
2026-06-30 Remove duplicate optional camera image
